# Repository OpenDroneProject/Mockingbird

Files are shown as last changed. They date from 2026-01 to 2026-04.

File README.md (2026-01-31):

# MockingBird

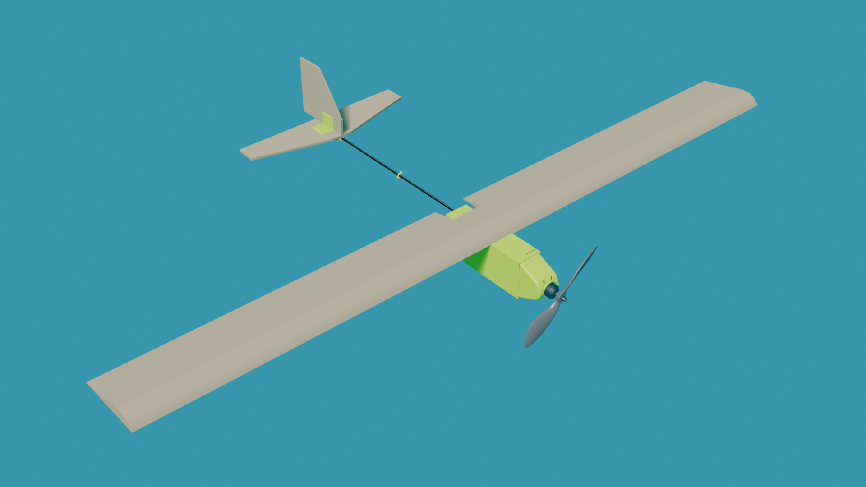
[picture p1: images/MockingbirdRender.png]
Mockingbird Render
    
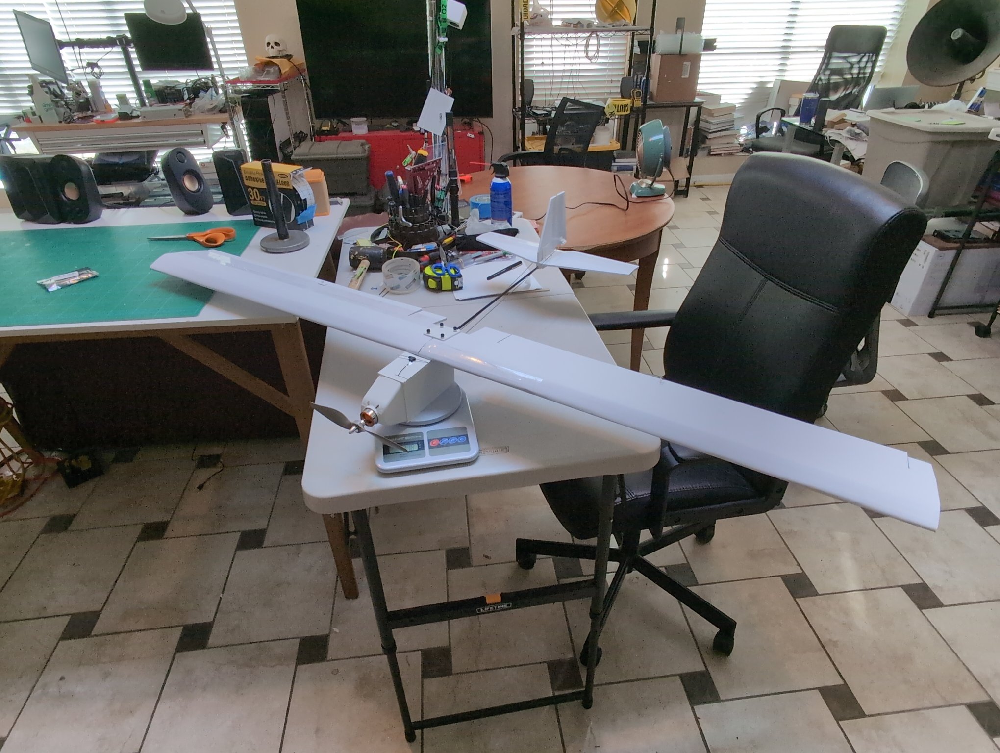
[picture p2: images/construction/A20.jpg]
Mockingbird Prototype
  

Mockingbird is intended to be the cheapest and simplest drone to make. Here are some stats:

- $90 cost per unit (not counting autonomy or FPV)
- Printable on a Bambu A1 Mini
- 745g (not counting autonomy or FPV)
- 1680g Static Thrust
- ~8 hours to build (most of that is 3D printer time)
- Adjustable Center of Lift
- Modular design, swap out the wings, tailfin, motor, battery, receiver, etc.

More detailed specs available on the [specs page](./SPECS.md).

[Bill of Materials](./BILL_OF_MATERIALS.md)  
[Assembly Guide](./ASSEMBLY.md)  
[Electronics Setup](./ELECTRONICS_SETUP.md)  

## Making the PDF
The `build_book.sh` script is a utility that turns the markdown files in this repo into a PDF.

If rust is not installed run `curl --proto '=https' --tlsv1.2 -sSf https://sh.rustup.rs | sh`

```bash
cargo install mdbook
./build_book.sh
mdbook serve book/
```

Download the webpage as a PDF, or run:
```bash
cargo install mdbook-pdf                                                      
mdbook-pdf book/
```

This file is large (~500MB), and will not be stored in this repository.

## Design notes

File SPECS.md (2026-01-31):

# Specs

| Parameter | Value |
|---|---|
| Weight (with battery) | 745g |
| Estimated Static Thrust | 1686g |
| Max TWR | 2.26 |

*Thrust estimated with 3S battery, 1400KV motor, 8x4E prop*

# Wing Specs

| Parameter | Value |
|---|---|
| Planform | Rectangular |
| Taper Ratio | 1 |
| Chord | 0.15m |
| Span | 1.524m |
| Area | 0.2286m² |
| Aspect Ratio | 10.15 |

---

## Aspect Ratio

Aspect ratio describes how long and narrow a wing is relative to its width. A high aspect ratio wing (like a glider) is long and thin, while a low aspect ratio wing (like a fighter jet) is short and wide.

```math
AR = \frac{S^2}{A} = \frac{Span}{Chord}
```

Where:
- **S** = Wingspan
- **A** = Wing area
- **Chord** = Wing width (for rectangular wings)

**Effects on performance:**
- **Higher AR** (like ours at 10.15): Lower induced drag, better lift-to-drag ratio, more efficient at slow speeds, better glide performance. Trade-off: requires stronger wing structure due to increased bending moment.
- **Lower AR**: Better roll rate and maneuverability, structurally stronger, but less aerodynamically efficient.

Our aspect ratio of ~10 is in the efficient range for slow-flying aircraft—similar to sailplanes and trainers.

---

## Wing Loading

Wing loading is the ratio of aircraft weight to wing area. It determines how "hard" the wing must work to generate lift and directly affects stall speed, handling, and flight characteristics.

```math
W_L = \frac{W}{A}
```

Where:
- **W** = Aircraft weight
- **A** = Wing area

**Effects on performance:**
- **Lower wing loading**: Slower stall speed, gentler handling, more affected by wind gusts, better for slow flight and easy landings.
- **Higher wing loading**: Faster stall speed, more stable in turbulence, better high-speed performance, but requires more runway.

---

## Stall Speed

Stall speed is the minimum airspeed at which the wing can generate enough lift to support the aircraft's weight. Below this speed, the wing stalls and lift drops dramatically.

Wing loading and stall speed are related by:

```math
W_L = \frac{1}{2} \rho V_{stall}^2 C_{L_{max}}
```

Solving for stall speed:

```math
V_{stall} = \sqrt{\frac{2 \cdot W_L}{\rho \cdot C_{L_{max}}}}
```

Where:
- **ρ (rho)** = Air density = 1.225 kg/m³ (at sea level)
- **C_L_max** = Maximum lift coefficient ≈ 1.5 (typical for flat-bottom airfoils)
- **W_L** = Wing loading (W/A)

---

## Glide Ratio (Estimated)

Glide ratio (L/D) is how far the aircraft travels forward for each unit of altitude lost—a 10:1 ratio means gliding 10m forward for every 1m of descent.

**Estimated glide ratio: ~8-10:1**

This estimate is based on:
- High aspect ratio (10.15) — reduces induced drag
- Rectangular planform — less efficient than tapered wings
- Flat-bottom airfoil — good for slow flight, not optimized for L/D
- Fuselage/pod — adds parasite drag

| Aircraft Type | Typical Glide Ratio |
|---|---|
| Typical RC trainer | 6-10:1 |
| **This plane (estimate)** | **~8-10:1** |
| Cessna 172 | ~9:1 |
| High-performance sailplane | 30-60:1 |

At 8:1, from 100m altitude you'd glide about 800m in still air.

---

## Performance Curves

**Wing Loading at 745g: ~3.3 kg/m²**

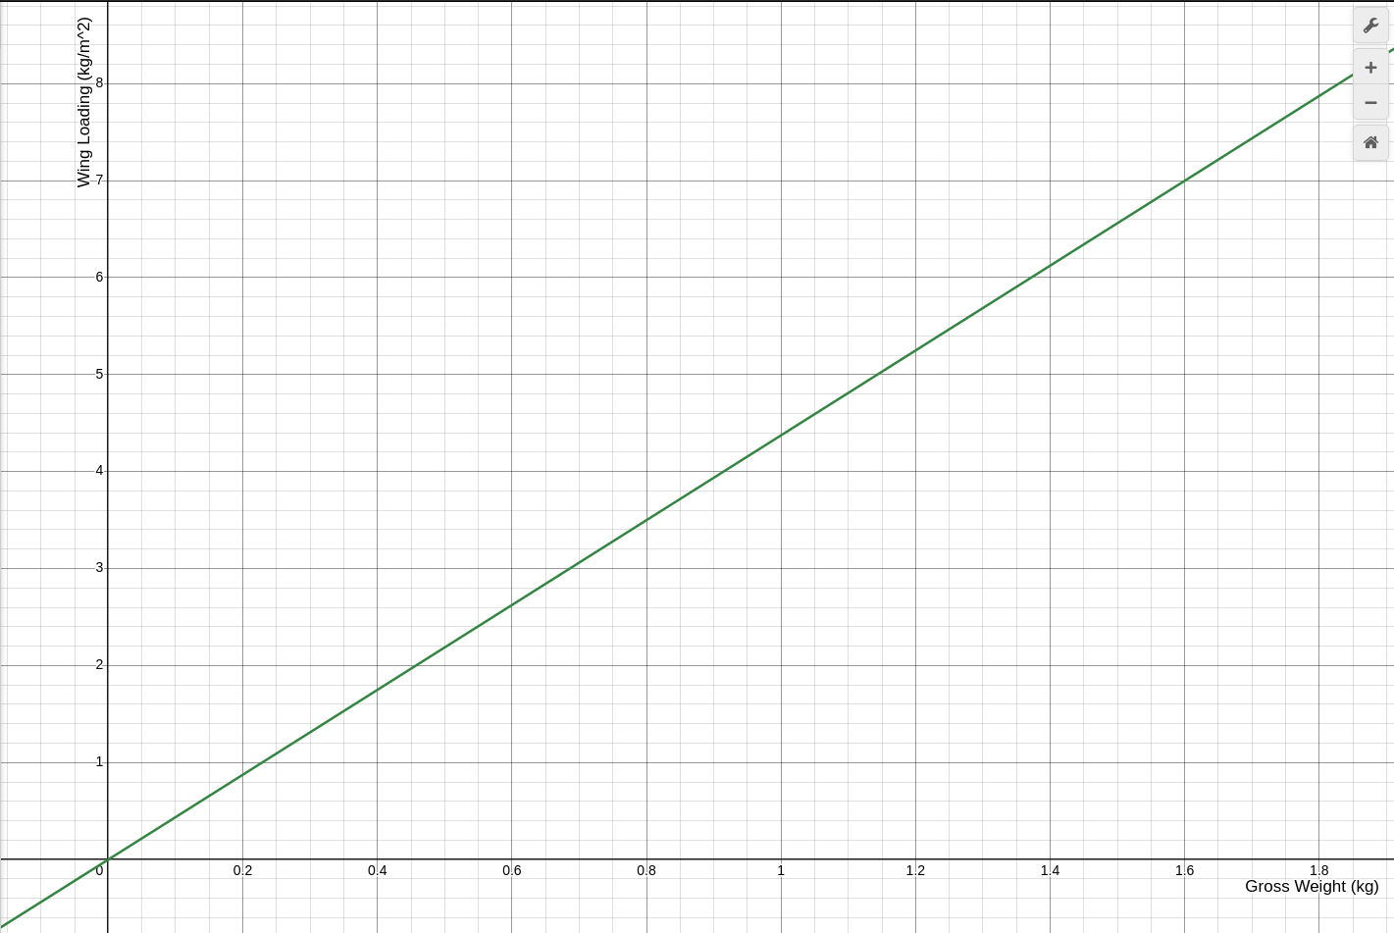
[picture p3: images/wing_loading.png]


**Stall Speed at 745g: ~5.8 m/s (13 mph)**

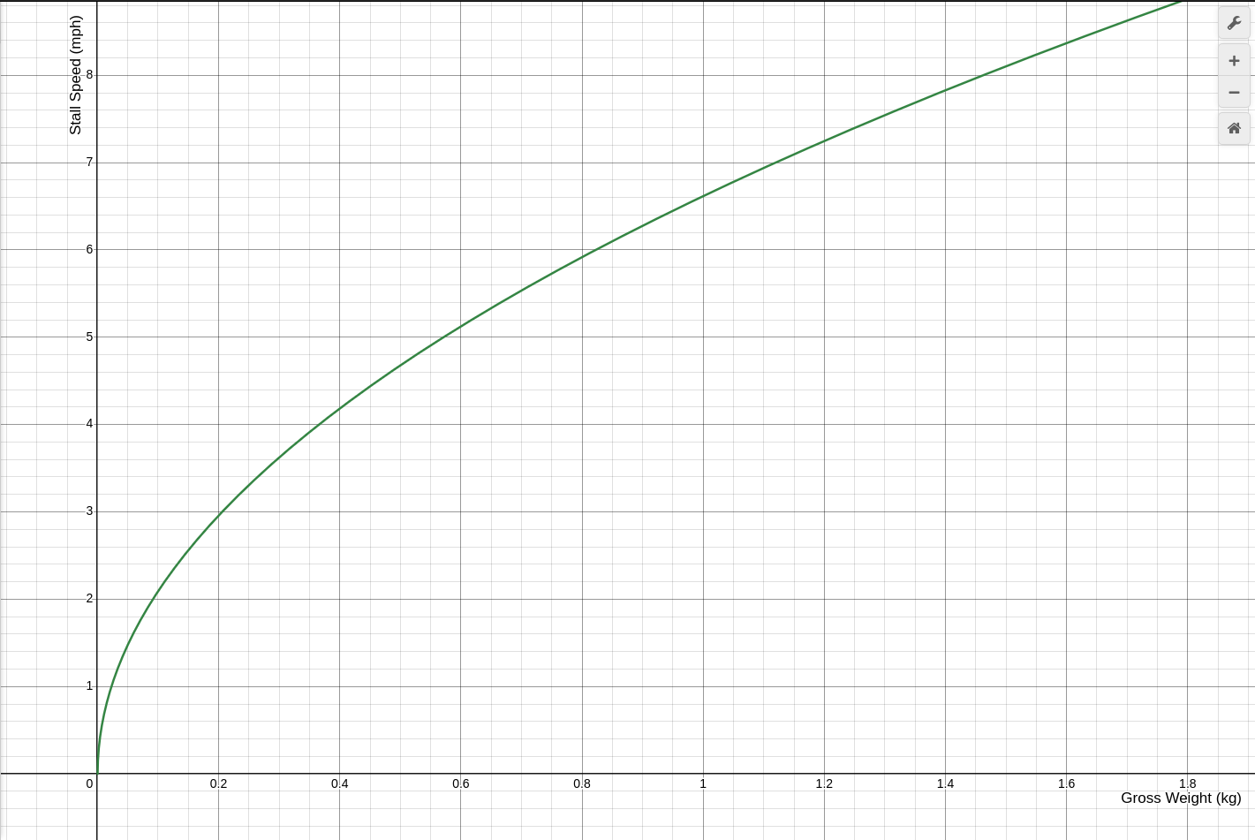
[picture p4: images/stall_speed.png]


---

## References

- [Aspect Ratio (Aeronautics) - Wikipedia](https://en.wikipedia.org/wiki/Aspect_ratio_(aeronautics))
- [How Does Aspect Ratio Affect Your Wing? - Boldmethod](https://www.boldmethod.com/learn-to-fly/aircraft-systems/how-does-aspect-ratio-affect-aircraft-wings/)
- [Aircraft Wing Area and Aspect Ratio - AeroToolbox](https://aerotoolbox.com/intro-wing-design/)
- [NASA Geometry Definitions](https://www.grc.nasa.gov/www/k-12/VirtualAero/BottleRocket/airplane/geom.html)

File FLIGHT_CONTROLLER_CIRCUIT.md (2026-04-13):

# Flight Controller Circuit Design

Custom fixed-wing flight controller stack designed for INAV. Supports IMU, GNSS, analog VTX, analog camera, and ELRS receiver. Servo and ELRS pins are hand-soldered Dupont headers by the end user.

---

## Development Strategy

A "strangler fig" approach is used — each custom board is validated against the SpeedyBee F405 Wing Mini before the next is designed. At every stage a fully functional flying system exists with only one new unknown variable.

| Stage | PDB | FC | Flasher |
|---|-----|----|---|
| 1 | SpeedyBee | SpeedyBee | **Ours** |
| 2 | **Ours** | SpeedyBee | Ours |
| 3 | Ours | **Ours** | Ours |

### Open Items Before Starting
- Measure the SpeedyBee FC board's USB extender connector pinout (physical silkscreen + continuity check)
- Measure the SpeedyBee PDB↔FC 12-pin stacking connector pinout (physical silkscreen + continuity check)

---

## Stack Architecture

Three permanent boards stack from bottom to top via 2×6 2.54mm stacking pin headers:

```
┌─────────────────────┐
│      FC Board       │  STM32F405, IMU, OSD, all JST connectors
└─────────────────────┘
           ↕  2×6 stacking header
┌─────────────────────┐
│      PDB Board      │  Battery input, 5V BEC, 6V BEC
└─────────────────────┘
```

The flasher accessory board is not a permanent stack member. It connects to the FC board via a cable when flashing is needed.

---

## Inter-Board Connectors

### PDB → FC (2×6 2.54mm stacking header)

| Pin | Row A | Row B |
|-----|---|---|
| 1 | GND | GND |
| 2 | GND | GND |
| 3 | VBAT | VBAT |
| 4 | 5V | 5V |
| 5 | 6V | 6V |
| 6 | SPARE | SPARE |

### FC → Flasher (JST SH 1.0mm 10-pin)

| Pin | Signal |
|-----|---|
| 1 | GND |
| 2 | GND |
| 3 | 5V |
| 4 | 3.3V |
| 5 | USB D+ |
| 6 | USB D− |
| 7 | BOOT0 |
| 8 | NRST |
| 9 | SWDIO |
| 10 | SWDCLK |

---

## Board 1: PDB (Power Distribution Board)

### Purpose
Battery input, spike suppression, reverse polarity protection, and regulated power output to the FC board.

### Large Solder Pads
- **Battery +/−** — main input, sized for XT30 (small wing) or XT60 (larger). Size for 16AWG minimum.
- **ESC +/−** — motor ESC wires solder directly here, on the same high-current copper pour as battery pads
- **Capacitor +/−** — for bulk low-ESR capacitor, same pour

Battery, ESC, and cap pads should all connect on the same wide copper pour. Keep traces short and fat.

### Bill of Materials

#### Power Input & Protection
| Component | Part | Notes |
|---|---|---|
| Bulk capacitor | Panasonic EEUFR1V471 — 470µF 35V low-ESR electrolytic | Through-hole solder pad footprint |
| TVS diode | SMBJ15A (3S) or SMBJ20A (4S) | Select based on max battery voltage |
| Reverse polarity MOSFET | AO4407 (SOP-8, 30V, 12A) | P-channel; gate resistor per datasheet |

#### 5V BEC (~2A)
Powers FC logic, GPS, ELRS, camera, VTX.

| Component | Part | Notes |
|---|---|---|
| Regulator IC | MP2315GJ-Z | 3A synchronous buck, up to 24V input |
| Inductor | Würth 744043100 — 10µH 3A | Or equivalent |
| Supporting passives | Per MP2315 datasheet | Bootstrap cap, input/output caps, feedback resistors |

#### 6V BEC (~3A)
Powers servos.

| Component | Part | Notes |
|---|---|---|
| Regulator IC | MP1584EN | 3A adjustable buck, up to 28V input |
| Inductor | Würth 744043047 — 4.7µH 3A | Or equivalent |
| Supporting passives | Per MP1584 datasheet | Output voltage set by feedback resistor divider |

#### Connectors & Indicators
| Component | Part | Notes |
|---|---|---|
| Stack header | 2×6 2.54mm male through-hole pin header | Pins pointing up toward FC board |
| Battery pads | Large through-hole pads, 2mm drill | Size for 16AWG wire minimum |
| ESC pads | Large through-hole pads, 2mm drill | Same |
| Capacitor pads | Through-hole pads to match cap lead spacing | Match EEUFR1V471 footprint |
| Power LED | 0402 red LED + 1kΩ resistor | On 5V rail |

### Implementation Plan

1. **Schematic (KiCad)**
   - Draw reverse polarity protection: AO4407 gate tied to GND through resistor, source on VBAT+, drain feeds internal VBAT rail
   - Draw 5V BEC using MP2315 application circuit from datasheet
   - Draw 6V BEC using MP1584 application circuit — set output to 6V via feedback resistor values (datasheet provides formula)
   - Connect VBAT, 5V, 6V, and GND pins to the 2×6 stack connector symbol
   - Add large pad symbols for battery, ESC, and capacitor

2. **Layout (KiCad)**
   - Place battery, ESC, and cap pads first along one edge
   - Place TVS and reverse polarity MOSFET immediately adjacent to battery pads, before anything else in the power path
   - Place each BEC circuit close to its output pin on the stack connector
   - Flood the board with GND and VBAT copper pours on opposite layers — keep high-current paths wide and short
   - Route 5V and 6V as wide traces from BEC output caps to stack connector
   - Keep BEC switching nodes (SW pin, inductor) compact to minimize EMI
   - Place power LED near the stack connector edge

3. **Review**
   - Run KiCad DRC — zero errors before ordering
   - Manually verify feedback resistor values produce correct output voltages
   - Check inductor and capacitor voltage/current ratings against worst-case inputs

4. **Fabrication**
   - 2-layer board is sufficient — no high-speed signals
   - Order from JLCPCB; hand-solder through-hole components, SMT assembly optional for BEC ICs

### Success Criteria

**Before applying power**
- Continuity between all GND pads
- No continuity between VBAT, 5V, 6V, or GND rails to each other
- High resistance (MOhm range) from VBAT+ to VBAT− — confirms no dead shorts

**On first power-up**
- Use a bench PSU set to battery voltage with 500mA current limit — if it folds back immediately there is a short
- Power LED illuminates
- Stack connector pin readings:

| Pin | Expected |
|-----|---|
| GND | 0V reference |
| VBAT | Matches PSU output |
| 5V | 4.9–5.1V |
| 6V | 5.9–6.1V |
| All other pins | 0V or floating |

**Under load**
- Connect dummy load (~500mA on 5V, ~1A on 6V) — voltages stay within ±0.2V of target
- BEC ICs and inductors warm but not hot after 60 seconds

---

## Board 2: FC Board (Flight Controller)

### Purpose
Main flight controller. Hosts the STM32F405RGT6, IMU, OSD chip, and all external connectors for GPS, ELRS, camera, and VTX.

### Bill of Materials

#### Microcontroller
| Component | Part | Notes |
|---|---|---|
| MCU | STM32F405RGT6 | LQFP-64 |
| HSE crystal | Abracon ABM8-8.000MHZ-B2-T — 8MHz | ±20ppm |
| Crystal load caps | 22pF 0402 × 2 | Per crystal datasheet |
| VCAP caps | 1µF 0402 × 2 | VCAP1 and VCAP2 — must be isolated from 3.3V rail |
| BOOT0 pull-down | 10kΩ 0402 | Boots from flash by default; stack/flasher connector overrides |
| NRST filter cap | 100nF 0402 | |
| Decoupling caps | 100nF + 4.7µF at every VDD/VDDA/VDDIO pin | Per STM32F405 datasheet |

> **Note:** VCAP1 and VCAP2 are the output pins of the STM32's internal 1.2V core regulator. They require dedicated 1µF caps to GND and must NOT connect to the 3.3V net. This is a common first-timer mistake.

#### Power
| Component | Part | Notes |
|---|---|---|
| 3.3V LDO | AP2112K-3.3 | SOT-25; takes 5V from stack connector |
| Decoupling caps | Per AP2112K datasheet | |

#### IMU
| Component | Part | Notes |
|---|---|---|
| IMU | ICM-42688-P | SPI interface |
| VDD ferrite bead | 100Ω @ 100MHz | Filters switching noise on IMU supply |
| Decoupling caps | 100nF + 1µF | Per ICM-42688-P datasheet |

#### OSD
| Component | Part | Notes |
|---|---|---|
| OSD chip | AT7456E | SPI to MCU; sits in the video path between camera and VTX |
| Decoupling caps | Per AT7456E datasheet | |

#### JST SH 1.0mm Receptacles
| Connector | Pins | Signals |
|---|---|---|
| GPS | 4 | GND, 5V, TX, RX |
| ELRS | 4 | GND, 5V, TX, RX |
| Camera | 3 | GND, 5V, video in → AT7456E |
| VTX | 4 | GND, 5V, video out from AT7456E, SmartAudio UART TX |

#### Servo Output Pads
- Through-hole 3-pin groups (GND, 6V, signal) × 6
- End user hand-solders male Dupont headers
- Suggested channels: aileron ×2, elevator, rudder, throttle, flaps

#### Voltage Sensing
- Resistor divider from VBAT (stack connector) to STM32 ADC pin
- Allows INAV to report battery voltage in OSD and trigger low-voltage warnings

#### Indicators & Misc
| Component | Part | Notes |
|---|---|---|
| Status LED | 0402 LED + resistor | GPIO-controlled; INAV uses for arming state |
| Buzzer pad | 2-pin through-hole | Passive buzzer for INAV alerts and lost-model beeper |

#### Connectors
| Component | Part | Notes |
|---|---|---|
| PDB stack connector | 2×6 2.54mm female socket (bottom of board) | Mates with PDB stacking header |
| Flasher connector | JST SH 1.0mm 10-pin receptacle | For flasher accessory board cable |

---

## Board 3: Flasher Accessory Board

### Purpose
Connects to the FC board to provide USB-C flashing capability. Not a permanent stack member — attach when flashing, remove during flight. Designed in two versions: one compatible with the SpeedyBee F405 Wing Mini (Stage 1), and one for our custom FC board (Stage 3).

### Stage 1: SpeedyBee-Compatible Flasher

The SpeedyBee FC board exposes a programming interface via its "Wireless USB Extender" connector. Our flasher board mates with this connector and replaces the SpeedyBee wireless extender with a direct USB-C connection.

> **Required before design:** Measure the SpeedyBee FC board's USB extender connector — note connector type, pin count, and silkscreen labels. Confirm with continuity check which pins carry D+, D−, 5V, GND, and whether BOOT0/NRST are exposed.

#### Bill of Materials

| Component | Part | Notes |
|---|---|---|
| USB-C receptacle | GCT USB4135-GF-A | Mid-mount, low profile |
| ESD protection | USBLC6-2SC6 | On D+, D−, and VBUS |
| CC resistors | 5.1kΩ 0402 × 2 | CC1 and CC2 to GND — mandatory for USB-C device role |
| BOOT button | 3×6mm SMD tactile switch | Pulls BOOT0 high if SpeedyBee exposes it; otherwise used only for our custom FC |
| RESET button | 3×6mm SMD tactile switch | Pulls NRST low if SpeedyBee exposes it; otherwise used only for our custom FC |
| Power LED | 0402 LED + 1kΩ resistor | Confirms VBUS is live |
| Decoupling caps | 10µF + 100nF on VBUS | |
| FC connector | TBD — match SpeedyBee USB extender port | Pinout to be measured from physical board |

#### Flashing Procedure (SpeedyBee)
1. Plug flasher board into SpeedyBee USB extender port
2. Connect USB-C to computer
3. Enter DFU mode per SpeedyBee's method (may differ from our custom FC)
4. Flash via INAV Configurator

---

### Stage 3: Custom FC Flasher

Once the custom FC board is designed, the flasher connects via JST SH 1.0mm 10-pin cable. The BOM is identical to the Stage 1 flasher except the FC connector changes.

| Component | Part | Notes |
|---|---|---|
| USB-C receptacle | GCT USB4135-GF-A | Mid-mount, low profile |
| ESD protection | USBLC6-2SC6 | On D+, D−, and VBUS |
| CC resistors | 5.1kΩ 0402 × 2 | CC1 and CC2 to GND |
| BOOT button | 3×6mm SMD tactile switch | Pulls BOOT0 high via JST connector |
| RESET button | 3×6mm SMD tactile switch | Pulls NRST low via JST connector |
| Power LED | 0402 LED + 1kΩ resistor | Confirms VBUS is live |
| Decoupling caps | 10µF + 100nF on VBUS | |
| JST SH 1.0mm receptacle | 10-pin | Connects to custom FC board |

#### Flashing Procedure (Custom FC)
1. Connect flasher board to FC board via JST cable
2. Hold BOOT button
3. Press and release RESET
4. Release BOOT — MCU is now in USB DFU mode
5. Open INAV Configurator and flash firmware

> No LDO needed on either flasher version. 5V from VBUS passes directly to the FC board. The custom FC board's AP2112K generates 3.3V from that; the SpeedyBee has its own onboard regulation.

---

## Cost Estimates

Rough estimates for a first run of 5 boards from JLCPCB, components sourced from LCSC.

### Per-Board Component Cost

#### Flasher Board (~$4–6)
| Item | Cost |
|---|---|
| PCB (2-layer, ~30×20mm, qty 5) | ~$0.50 |
| GCT USB4135-GF-A | ~$0.80 |
| USBLC6-2SC6 | ~$0.30 |
| Tactile switches ×2 | ~$0.20 |
| JST SH 1.0mm 10-pin receptacle | ~$0.40 |
| Passives, LED | ~$0.20 |
| **Total** | **~$2.40** |

#### PDB (~$8–12)
| Item | Cost |
|---|---|
| PCB (2-layer, ~40×40mm, qty 5) | ~$0.60 |
| MP2315GJ-Z (5V BEC) | ~$1.20 |
| MP1584EN (6V BEC) | ~$0.80 |
| Würth inductors ×2 | ~$2.50 |
| Panasonic EEUFR1V471 cap | ~$0.80 |
| AO4407 MOSFET | ~$0.40 |
| SMBJ15A TVS | ~$0.30 |
| 2×6 pin header | ~$0.30 |
| Passives, LED | ~$0.30 |
| **Total** | **~$7.20** |

#### FC Board (~$25–35)
| Item | Cost |
|---|---|
| PCB (4-layer, ~35×35mm, qty 5) | ~$2.50 |
| STM32F405RGT6 | ~$7.00 |
| ICM-42688-P | ~$3.50 |
| AT7456E | ~$3.00 |
| AP2112K-3.3 LDO | ~$0.40 |
| 8MHz crystal | ~$0.40 |
| JST SH 1.0mm receptacles ×4 | ~$1.60 |
| 2×6 female socket + JST SH 10-pin | ~$0.60 |
| Passives, LED, crystal caps | ~$1.50 |
| **Total** | **~$20.50** |

### First-Run Total (qty 5)

| Board | Components | PCB | JLCPCB SMT Setup | First Run (qty 5) |
|---|---|-----|---|---|
| Flasher | ~$12 | ~$2.50 | ~$15 | ~$30 |
| PDB | ~$36 | ~$3 | ~$20 | ~$60 |
| FC | ~$103 | ~$12.50 | ~$30 | ~$145 |
| **Total** | | | | **~$235** |

### Notes
- JLCPCB SMT setup fees (~$8–20 per unique extended part) dominate at low quantities — per-unit cost drops significantly at qty 10+
- The STM32F405RGT6 is the single biggest cost driver — fine-pitch LQFP-64, SMT assembly strongly recommended over hand-soldering
- ICM-42688-P and AT7456E are also fine-pitch and should be assembled by JLCPCB
- Parts in JLCPCB's Basic parts library have no setup fee — check there first when choosing passives and common ICs
- A second revision typically costs much less since setup fees are not paid again

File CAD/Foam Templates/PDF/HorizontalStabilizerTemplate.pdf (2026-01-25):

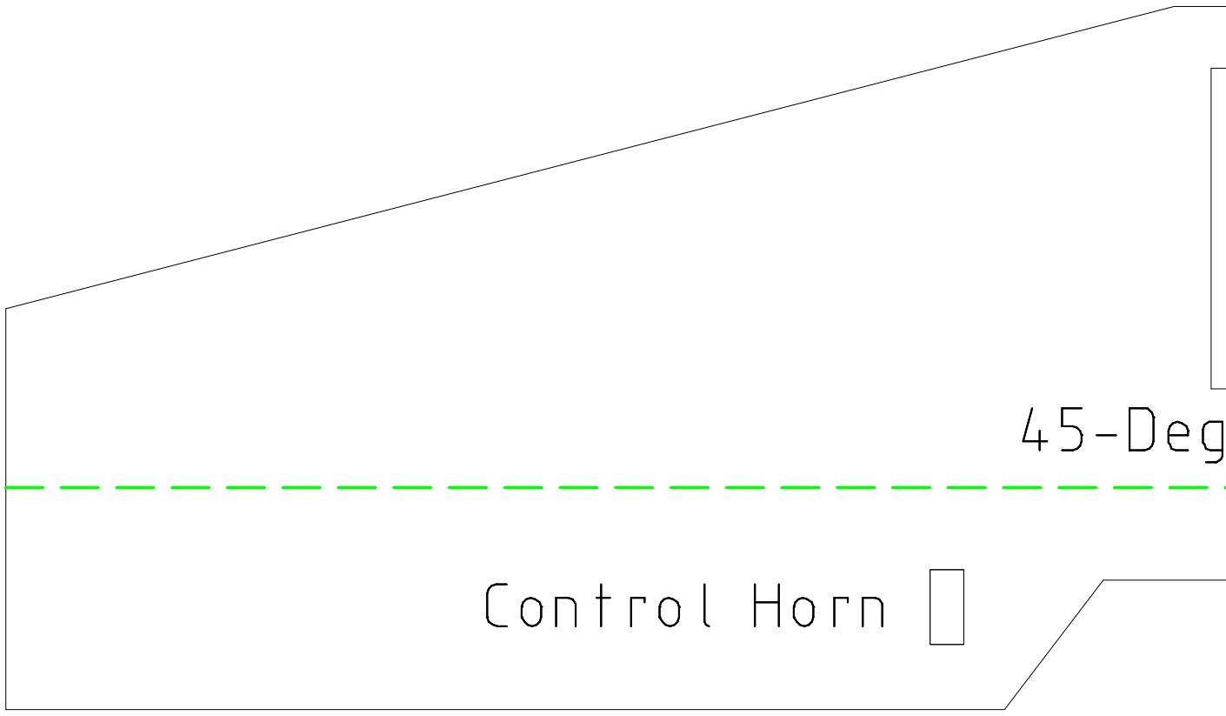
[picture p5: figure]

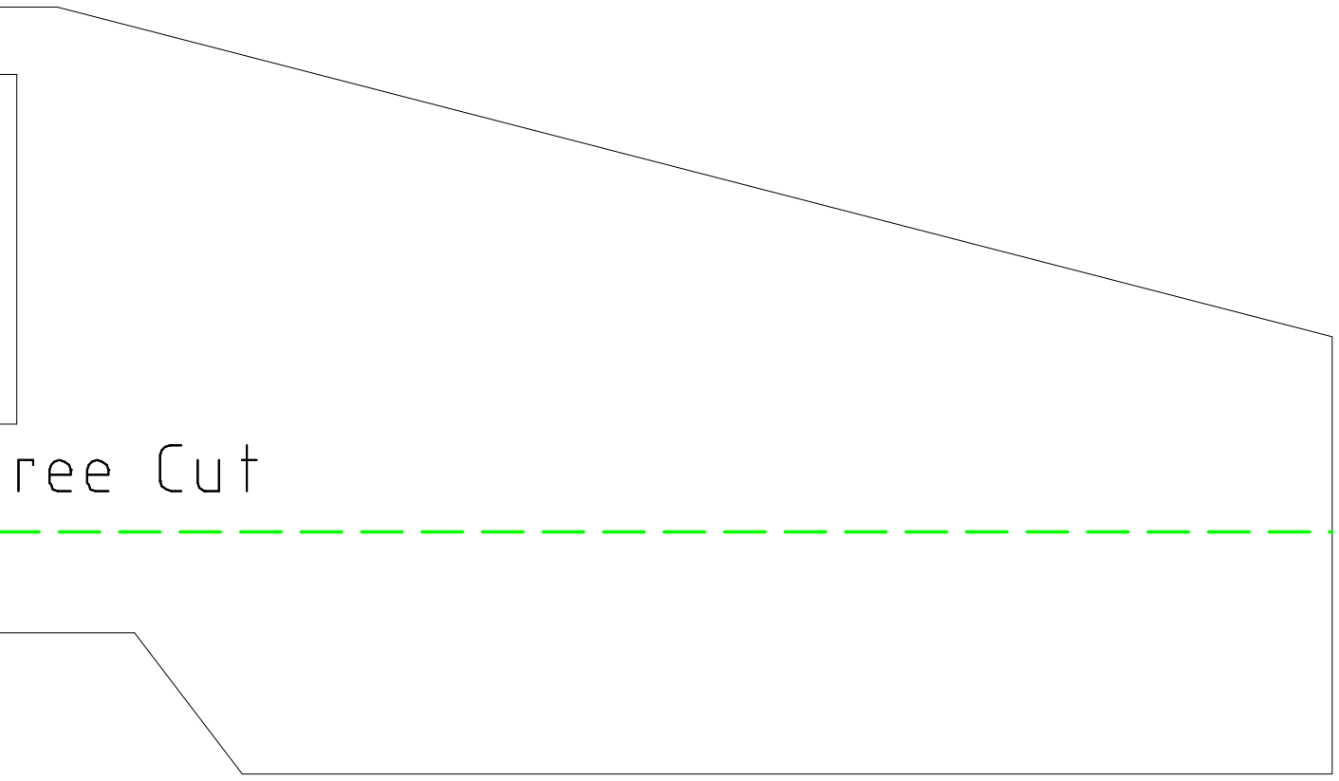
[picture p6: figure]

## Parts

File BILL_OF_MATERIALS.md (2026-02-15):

# Bill of Materials

## Tools

Comprehensive list of tools you will need for this build.

### Assembly

| Item |
|------|
| Bambu A1 Mini or Larger |  
| X-Acto knife |  
| Cutting surface |  
| Metal Ruler |
| Large Hot Glue gun | 
| Large Hot Glue sticks | 
| Packing tape | 
| Fine sharpie | 
| Masking tape | 
| Twist ties (optional) | 
| Hex wrench set | 
| Small phillips head screwdriver | 
| Needle-nose pliers | 

### Flying

Any ELRS radio running EdgeTX or OpenTX will work. I just have the Radiomaster Pocket and I like it a lot for the price.

| Item | Cost | Link |
|---|---|---|
| RadioMaster Pocket | $80 | [link](https://www.amazon.com/Radiomaster-Pocket-Transmitter-Lightweight-ELRS-Charcoal/dp/B0DXPLH726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) |
| 18650 Battery for radio (2x) | $16 | [link](https://www.amazon.com/JESSY-Rechargeable-Battery-3-7V-Flashlights/dp/B0FCMD13RR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) |
| Battery Charger (2S/3S, XT60, balance socket) | $30-$50 | [link](https://www.amazon.com/Battery-Charger-Balance-Discharger-Batteries/dp/B0F5HPV5BR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) |

### Electronics Work

You will need a soldering iron to set up the SpeedyBee F405 Wing Mini. I recommend the Pinecil if you want something that doesn't take up a lot of space, although it is not particularly ergonomic.

| Item | Cost | Link |
|---|---|---|
| Pinecil soldering iron | $40 | [link](https://www.amazon.com/PINECIL-Smart-Mini-Portable-Soldering/dp/B096X6SG13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) |
| 100W USB-C charger for Pinecil | $30 | [link](https://www.amazon.com/Charger-Anker-Compact-Foldable-Included/dp/B0C1FZWT8M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) |
| Practice soldering boards (optional) | $14 | [link](https://www.amazon.com/Soldering-Practice-Beginner-Improving-Controller/dp/B0C5RBTHT1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) |

## Materials

### Materials Required for Base Drone Build

| Item | cost | qty for planes | cost per unit | Link |
|---|---|---|---|---|
| Adhesive Velcro | $10 | 360 | $0.03 | [link](https://www.amazon.com/dp/B0CGVPMJBP?ref=ppx_yo2ov_dt_b_fed_asin_title&th=1) |
| M2 screws | $10 | 25 | $0.40 | [link](https://www.amazon.com/Fgruh-1260pcs-M2-Assortment-Stainless/dp/B0FG2CC91J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) |
| M4 screws | $4 | 10 | $0.40 | [link](https://www.amazon.com/Assortment-Stainless-Washers-Printing-Projects/dp/B0DLNL2XJT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) |
| Push rods | $13 | 10 | $1.30 | [link](https://www.amazon.com/dp/B0B2LCJDPF?ref=ppx_yo2ov_dt_b_fed_asin_title) |
| 1.2mm wire | $10 | 20 | $0.50 | [link](https://www.amazon.com/uxcell-10Pcs-Stainless-Steel-Working/dp/B0DKXSRDC5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) |
| ELRS receiver | $19 | 1 | $19 | [link](https://www.amazon.com/dp/B09WHLJ2GN?ref=ppx_yo2ov_dt_b_fed_asin_title) |
| 30A ESC with XT60 and bullet plugs | $17 | 2 | $8.50 | [link](https://www.amazon.com/Electric-Brushless-Controller-Airplane-Helicopter/dp/B0CZNM4H7H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) |
| 9g servo | $16 | 2.5 | $6.40 | [link](https://www.amazon.com/dp/B09GFN98X9?ref=ppx_yo2ov_dt_b_fed_asin_title&th=1) |
| 5mm x 500mm carbon fiber rods | $10 | 5 | $2.00 | [link](https://www.amazon.com/MECCANIXITY-Carbon-Fiber-300mm-Quadcopter/dp/B0CTTBSBNN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) |
| 5mm OD x 4mm ID x 500mm L aluminum tube | $7  | 4 | $1.75 | [link](https://www.aliexpress.us/item/3256805305625604.html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) |
| PETG filament | $17 | 40 | $0.43 | [link](https://www.amazon.com/dp/B0FGTVG684?ref=ppx_yo2ov_dt_b_fed_asin_title&th=1) |
| AIR PLA filament | $25 | 40 | $0.63 | [link](https://www.amazon.com/OVERTURE-Filament-Cardboard-Dimensional-Probability/dp/B0BQRF32YY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) |
| 20"x30" 5mm foamboard | $28 | 5 | $5.60 | [link](https://www.amazon.com/UCreate%C2%AE-Board-White-Matte-Sheets/dp/B074QZMLQF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) |
| 2200mAh 3S | $34 | 2 | $17 | [link](https://www.amazon.com/OVONIC-2200mAh-Battery-Evader-Airplane/dp/B07DGSVNP5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) |
| 800-1400kv BR2208 motor | $12 | 1 | $12 | [link](https://www.amazon.com/dp/B08QZ95C98?ref=ppx_yo2ov_dt_b_fed_asin_title&th=1) |
| 6" servo cables | $10 | 2.5 | $4 | [link](https://www.amazon.com/dp/B07QJSWNFM?ref=ppx_yo2ov_dt_b_fed_asin_title) |
| servo Y-cable | $10 | 10 | $1 | [link](https://www.amazon.com/dp/B0CM6M6DKK?ref=ppx_yo2ov_dt_b_fed_asin_title&th=1) |
| 8x4 properller | $13 | 10 | $1.30 | [link](https://www.amazon.com/uxcell-Propellers-Fixed-Wing-Airplane-Adapter/dp/B07PWD3DSB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) |

**Startup Cost: $262**  
**Cost Per Unit: $88**

### BOM for Autonomy Upgrade

| Item | cost | qty for planes | cost per unit | Link |
|---|---|---|---|---|
| Speedybee F405 wing MINI | $36 | 1 | $36 | [link](https://www.speedybee.com/speedybee-f405-wing-mini-fixed-wing-flight-controller/) |
| XT60 cables | $16 | 10 | $1.60 | [link](https://www.amazon.com/dp/B0DPCFN6QT?ref=ppx_yo2ov_dt_b_fed_asin_title&th=1) |
| ELRS non-PWM | $24 | 1 | $24 | [link](https://www.amazon.com/dp/B0BGBKG635?ref=ppx_yo2ov_dt_b_fed_asin_title) |
| Beitian BN220 | $12 | 1 | $12 | [link](https://www.aliexpress.us/item/3256806167148761.html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) |

**Cost Per Unit: $74**

### BOM for FPV Upgrade

| Item | cost | qty for planes | cost per unit | Link |
|---|---|---|---|---|
| Camera  | $19 | 1 | $19 | [link](https://www.amazon.com/dp/B09SL2TRYF?ref=ppx_yo2ov_dt_b_fed_asin_title&th=1) |
| Antenna | $10 | 1 | $10 | [link](https://www.amazon.com/dp/B076H5QT2N?ref=ppx_yo2ov_dt_b_fed_asin_title&th=1) |
| VTX | $30 | 1 | $30 | [link](https://www.amazon.com/dp/B07YC1BSX6?ref=ppx_yo2ov_dt_b_fed_asin_title) |

**Cost Per Unit: $60**

# Mass Budget

## Electronics

| Item | Weight per unit | Qty | Total |
|---|---|-----|---|
| Battery | 172g | 1 | 172g  |
| ESC | 32g | 1 | 32g |
| ELRS Receiver | 15g | 1 | 15g |
| Motor | 41g | 1 | 41g |
| SG 90 Servos | 19g | 4 | 36g |
| 6" Servo Extenders  | 10g | 2 | 20g |
| Y Servo splitter | 10g | 1 | 10g |
| Velcro | ??? | ? | ??? |
| | | | 328g  |

## Aerofoils

| Item | Weight per unit | Qty | Total |
|---|---|-----|---|
| Wings | 220g | 1 | 220g  |
| Carbon Fiber Rod | 11g | 2 | 22g |
| Tailfin Assembly | 27g | 1 | 27g |
| M4 Screws | 3g | 4 | 12g |
| | | | 267g  |

## Pod

| Item | Weight per unit | Qty | Total |
|---|---|-----|---|
| Motor Mount | 18g | 1 | 18g |
| Pod | 56g | 1 | 56g |
| M2 Screws | 1.5g | 18  | 27g |
| Servo Holder | ??? | 2 | ??? |
| Front Fairing | ??? | 1 | ??? |
| Rear Fairing | ??? | 1 | ??? |
| Bottom Fairing | ??? | 1 | ??? |
| | | | 101g  |

TOTAL: 718g  
ACTUAL MEASURED: 745g  

## Autonomy
flight computer -- 42g
GNSS -- 15g

TOTAL + Autonomy: 780g

## FPV

TODO

## Construction Time

### 3D Printing Time

| Part | Time |
|---|---|
| Electronics Pod | 2hrs 20 mins |
| Motor Mount | 1hr 10 mins |
| Small Parts | 2hrs 30 mins |
| Front Fairing | 45 mins |
| Bottom Fairing | 1hr |
| Rear Fairing | ? |
| Top Fairing | 15 mins |
| Servo Fairings | 45 mins |
| **Total** | **6hr 45 mins** |

### Foamboard

| Task | Time |
|---|---|
| Template Print and Cutout | 20 mins (only needed first time) |
| Tailfin Cutout | 5 mins |
| Wing Fold | 30 mins per wing |
| **Total** | **~1hr** |

### Assembly

| Task | Time |
|---|---|
| Wing assembly | 30 mins |
| Body assembly | 30 mins |

### Testing and Electronics Config
??? Min

### Total

3D printing can be done while making the templates.

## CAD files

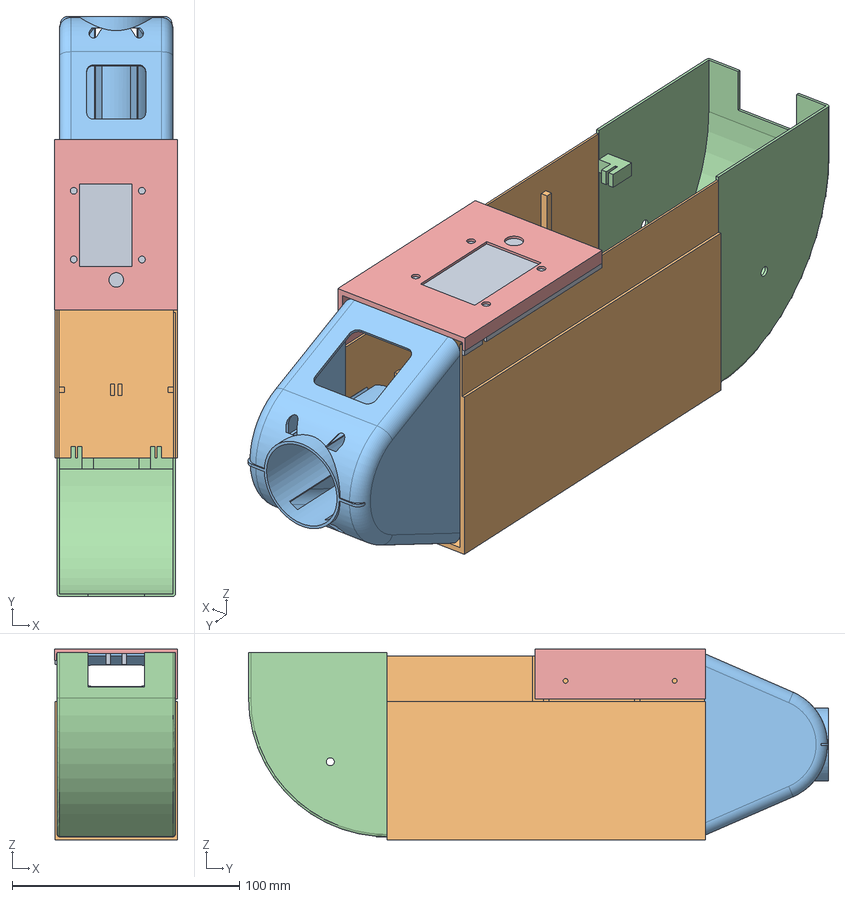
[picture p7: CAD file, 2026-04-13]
CAD/3D Printed Parts/FreeCAD Source Files/Mockingbird.FCStd
54.2 x 255.2 x 84.0 mm
TopFairing
BottomFairing
FrontFairing
RearFairing
TopFairingVTX

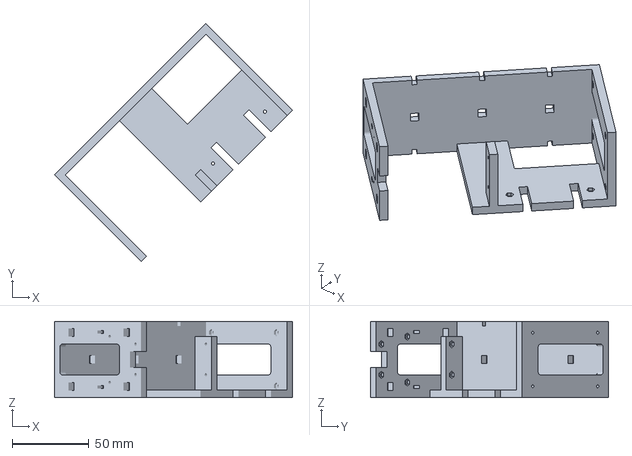
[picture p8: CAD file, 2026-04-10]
CAD/3D Printed Parts/GCODE/POD.3mf
155.6 x 155.6 x 50.0 mm

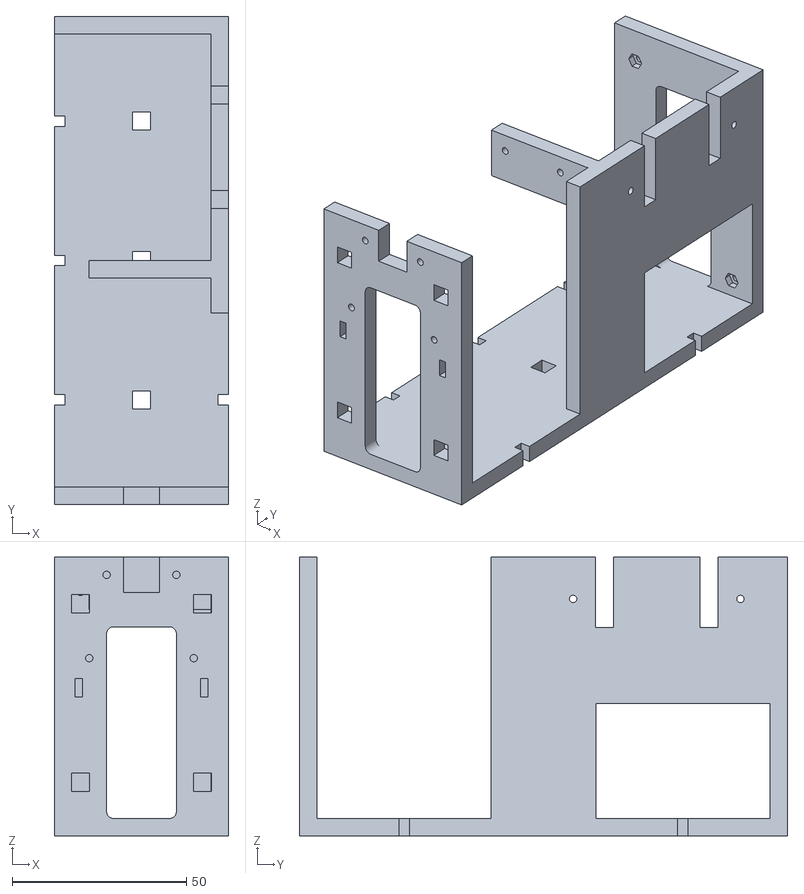
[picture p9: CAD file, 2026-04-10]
CAD/3D Printed Parts/STL/Pod.stl
50.0 x 140.0 x 80.0

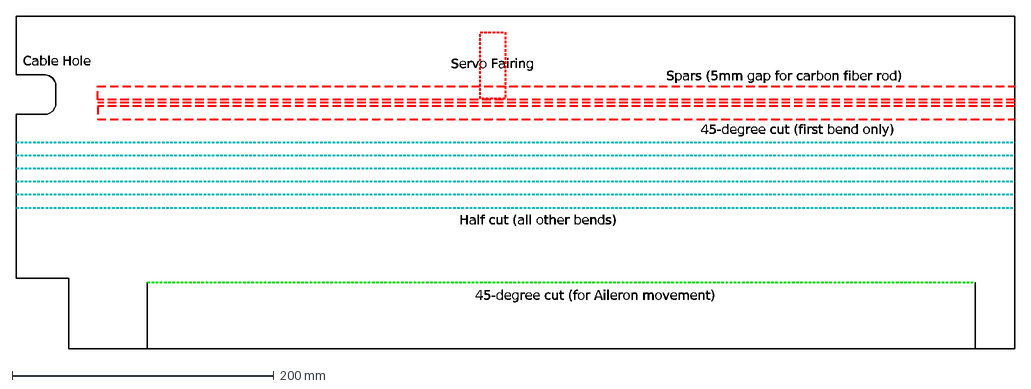
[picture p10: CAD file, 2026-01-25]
CAD/Foam Templates/DXF/LeftWingTemplate.dxf
Spars (5mm gap for carbon fiber rod)
Servo Fairing
Cable Hole
Half cut (all other bends)
45-degree cut (first bend only)
45-degree cut (for Aileron movement)

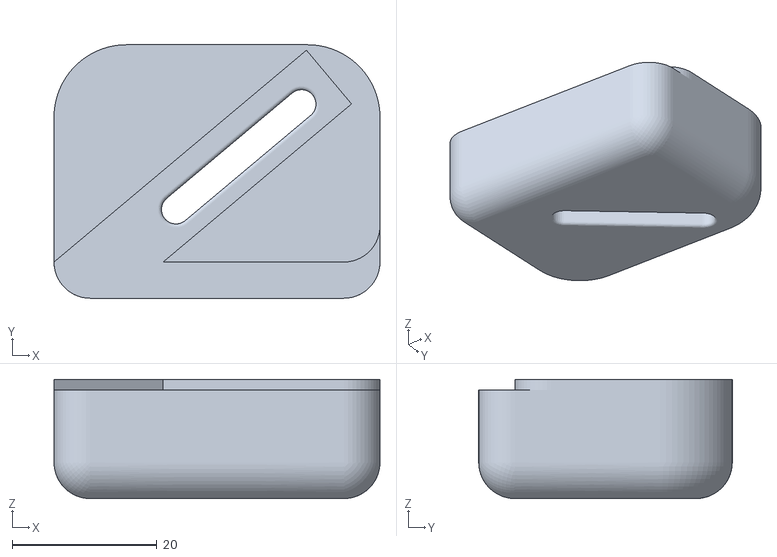
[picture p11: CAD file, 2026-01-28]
Utilities/Foam_board_90_degree_cutter.stl
45.0 x 35.0 x 16.5

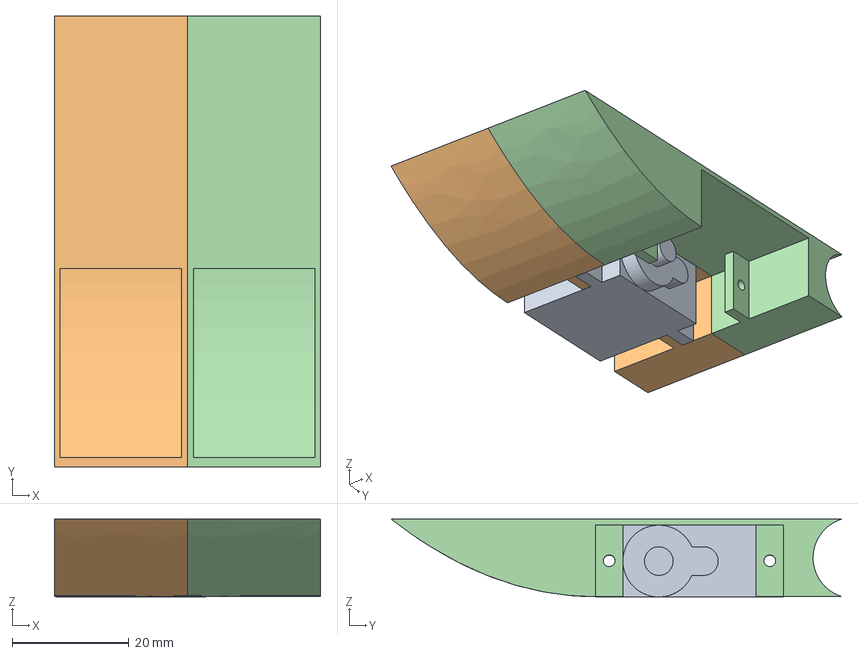
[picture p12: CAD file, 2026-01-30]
CAD/3D Printed Parts/FreeCAD Source Files/ServoFairing.FCStd
45.6 x 77.2 x 13.4 mm
ServoRef
LeftFairing
RightFairing

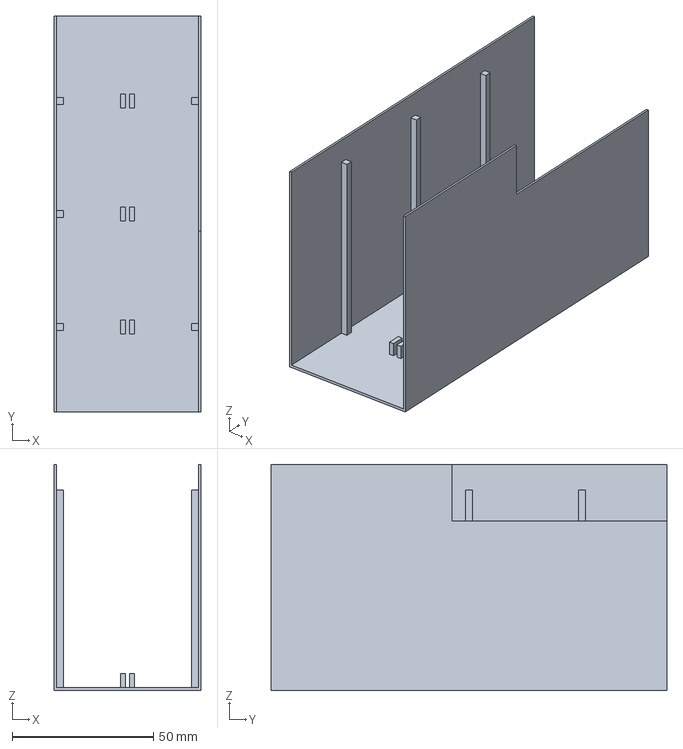
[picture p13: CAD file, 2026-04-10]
CAD/3D Printed Parts/GCODE/BOTTOM_FAIRING.3mf
52.0 x 140.0 x 80.0 mm

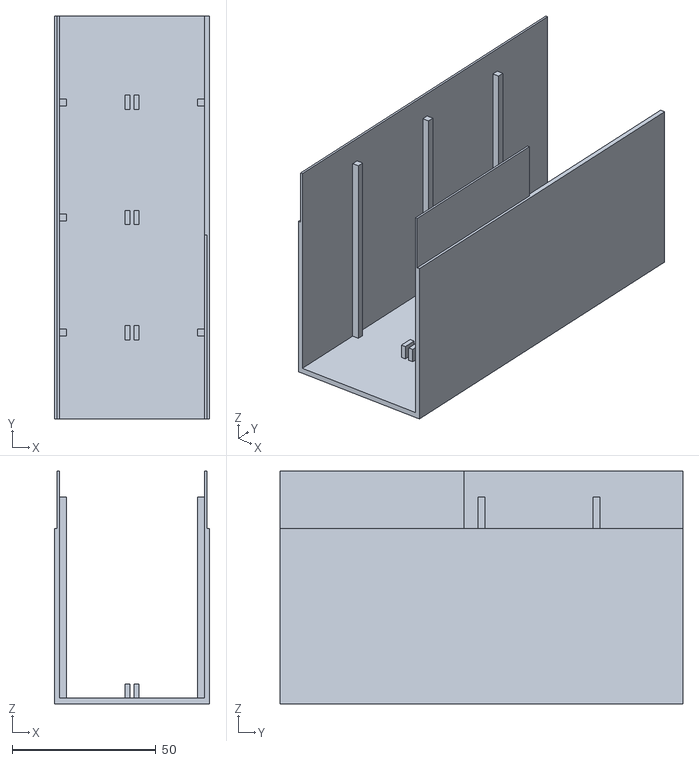
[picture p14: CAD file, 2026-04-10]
CAD/3D Printed Parts/STL/BottomFairing.stl
54.0 x 140.0 x 81.0

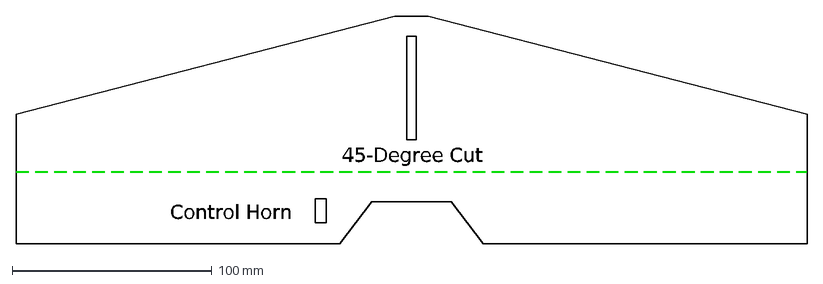
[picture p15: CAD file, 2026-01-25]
CAD/Foam Templates/DXF/HorizontalStabilizerTemplate.dxf
Control Horn
45-Degree Cut

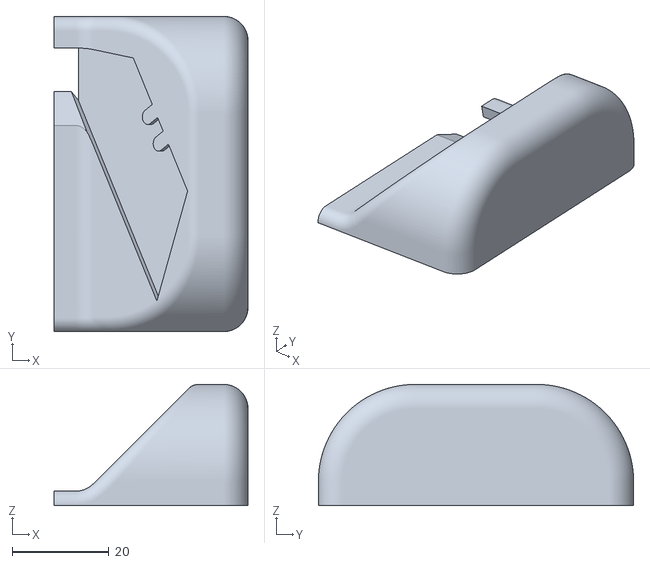
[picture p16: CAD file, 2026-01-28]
Utilities/5mmFoamBoardMiterCutter.stl
40.0 x 65.0 x 25.0

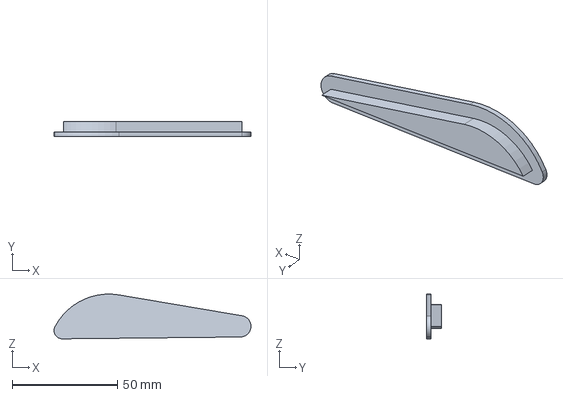
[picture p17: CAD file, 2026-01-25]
CAD/3D Printed Parts/FreeCAD Source Files/Winglet.FCStd
93.7 x 7.00 x 21.3 mm

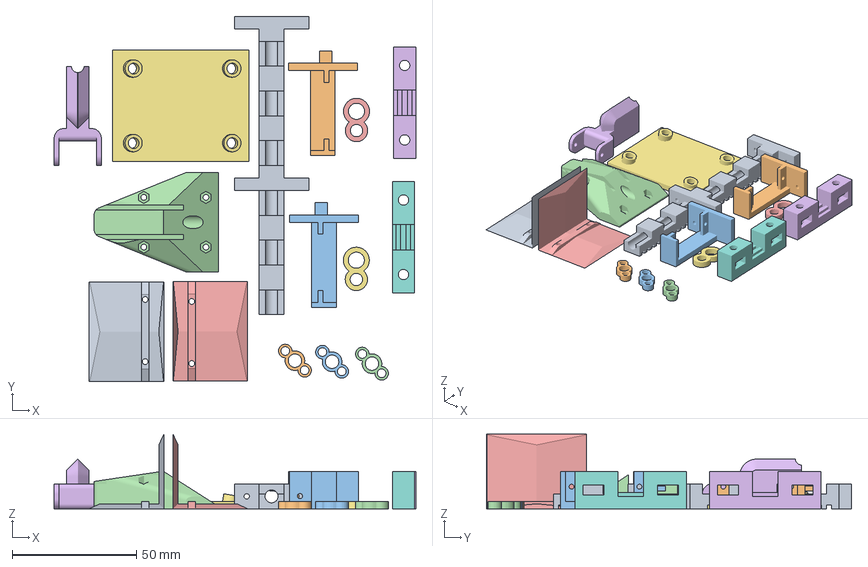
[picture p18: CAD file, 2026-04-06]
CAD/3D Printed Parts/GCODE/PETG_COMPONENTS.3mf
145.6 x 146.9 x 30.0 mm
Mockingbird_V1_Proto-CFTube001.stl
Mockingbird_V1_Proto-ServoMountPort.stl
Mockingbird_V1_Proto-ServoMountStarboard.stl
Mockingbird_V1_Proto-TailfinAdapter.stl
Mockingbird_V1_Proto-TailfinReinforcement.stl x 2
Mockingbird_V1_Proto-WingHolder.stl x 2
WingClamp-WingClamp.stl
WireGuide.stl x 3
CameraCableGuide.stl x 2
CameraMount.stl

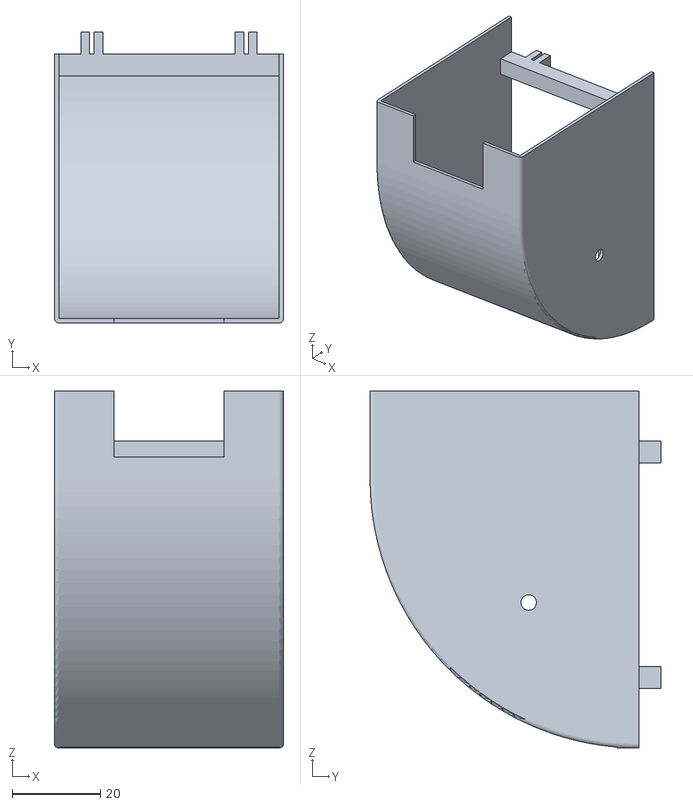
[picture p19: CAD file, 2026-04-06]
CAD/3D Printed Parts/STL/RearFairing.stl
52.0 x 66.0 x 81.0

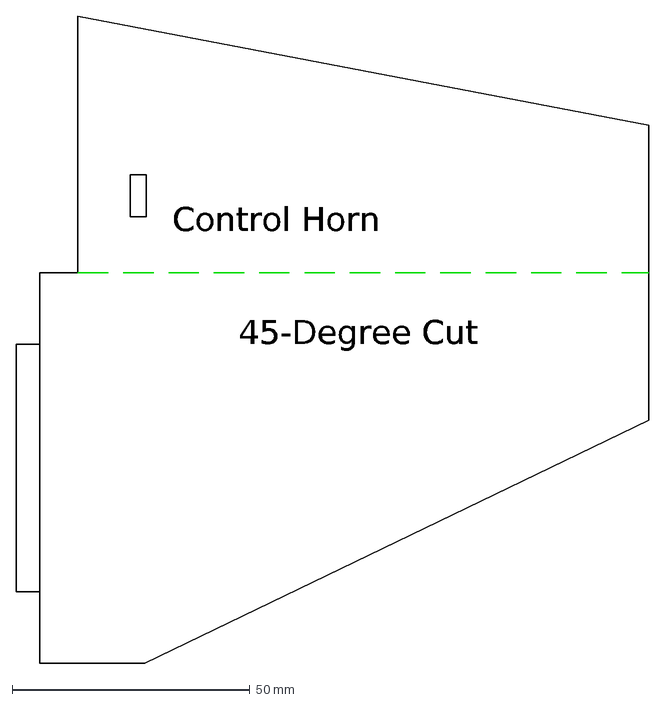
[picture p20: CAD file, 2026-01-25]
CAD/Foam Templates/DXF/VerticalStabilizerTemplate.dxf
Control Horn
45-Degree Cut

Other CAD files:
CAD/Foam Templates/FreeCAD Source/TailfinAssembly.FCStd
CAD/Foam Templates/FreeCAD Source/ArminWing.FCStd
Utilities/Servo-SG90.stl
CAD/3D Printed Parts/FreeCAD Source Files/WingClamp.FCStd
CAD/3D Printed Parts/FreeCAD Source Files/ControlHorns.FCStd
CAD/3D Printed Parts/GCODE/CONTROL.3mf
CAD/3D Printed Parts/GCODE/FRONT_FAIRING.3mf
CAD/3D Printed Parts/GCODE/MOTOR_MOUNT.3mf
CAD/3D Printed Parts/GCODE/SERVO_FAIRINGS.3mf
CAD/3D Printed Parts/GCODE/TOP_FAIRING.3mf
CAD/3D Printed Parts/GCODE/VTX_MOUNT.3mf
CAD/3D Printed Parts/STL/CameraCableGuide.stl
CAD/3D Printed Parts/STL/CameraMount.stl
CAD/3D Printed Parts/STL/ControlHorn.stl
CAD/3D Printed Parts/STL/ControlHornTab.stl
CAD/3D Printed Parts/STL/FrontFairing.stl
CAD/3D Printed Parts/STL/MotorMount.stl
CAD/3D Printed Parts/STL/ServoFairing-Left.stl
CAD/3D Printed Parts/STL/ServoFairing-Right.stl
CAD/3D Printed Parts/STL/ServoMountLeft.stl
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

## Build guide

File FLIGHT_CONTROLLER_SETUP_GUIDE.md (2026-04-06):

# Flight Controller Setup Guide: SpeedyBee F405 Wing Mini (INAV)

This guide covers the installation and configuration of the SpeedyBee F405 Wing Mini with the following hardware:
- **VTX:** AKK Race Ranger
- **Camera:** CADDX FPV Ant
- **GPS:** BN-880 (with Compass)
- **Receiver:** Radiomaster ELRS-RP3-V2
- **Radio:** Radiomaster Pocket
- **Goggles:** Eachine EV800D

---

## 1. Wiring & Custom Cables

### **A. GPS & Compass (BN-880)**
The BN-880 and the SpeedyBee F405 Wing Mini both use 6-pin SH1.0 connectors, but the **pinouts are different**. You must repin the cable or solder directly to the pads.

| BN-880 Pin | Function | FC Pad (Front) | FC Connector (Back) |
| :--- | :--- | :--- | :--- |
| 1 | SDA | SDA | Pin 1 (SDA) |
| 2 | GND | G | Pin 4 (G) |
| 3 | TX | RX3 | Pin 5 (RX3) |
| 4 | RX | TX3 | Pin 6 (TX3) |
| 5 | VCC (5V) | 4V5 | Pin 3 (V) |
| 6 | SCL | SCL | Pin 2 (SCL) |

**Note:** Connecting to `4V5` instead of `5V` or `V` allows the GPS and Receiver to be powered by the USB cable during configuration.

### **B. Servo Power & ESC Connection**
The SpeedyBee F405 Wing Mini has a unique power layout. By default, the servo pins (**Vx**) have **NO POWER**, even when a battery is plugged in.

1.  **Activate Servo BEC:** You MUST solder the two pads of the **"Servo BEC Power Supply Jumper"** on the **back of the PDB board** shut. This connects the internal 4.5A BEC to the servo rail.
2.  **ESC Wiring (S1):** For safety and reliability, use the FC's internal BEC to power servos, not the ESC's.
    *   **Depin Red Wire:** Use a small needle to lift the plastic tab on the ESC's 3-wire connector and pull the **Red (5V)** wire out. Wrap it in electrical tape.
    *   **Connect to S1:** Plug the ESC (now with only Signal and Ground) into the **S1** pins.
3.  **Servo Connections:** Plug your servos into **S2 (Roll), S3 (Pitch), and S4 (Yaw)**.

### **C. VTX & Camera (AKK Race Ranger & CADDX Ant)**
To ensure clean video, we will power the camera from the VTX's filtered 5V output.

1.  **VTX to FC:**
    - **7-26V In** -> **Vv** (Ensure the VTX Power Jumper on the PDB is set to **BAT** for 2S-6S).
    - **GND** -> **G**
    - **Video** -> **Vi** (Video Output from FC OSD)
    - **Smart Audio** -> **T5** (UART5 TX)
2.  **Camera to VTX/FC:**
    - **VCC** -> **AKK 5V Output**
    - **GND** -> **AKK GND**
    - **Video** -> **C1** (Video Input to FC OSD)

### **C. Receiver (Radiomaster RP3-V2)**
The RP3-V2 uses UART1.

- **5V** -> **4V5** (Powers RX via USB)
- **GND** -> **G**
- **TX** -> **RX1**
- **RX** -> **TX1**

---

## 2. Software Setup (INAV)

### **Linux-Specific Preparation**
If you are using Linux, you must grant permissions for your user to access the STM32 bootloader (DFU mode) and serial ports.

1.  **Create udev rule for DFU mode:**
    ```bash
    echo 'SUBSYSTEM=="usb", ATTRS{idVendor}=="0483", ATTRS{idProduct}=="df11", MODE="0664", GROUP="plugdev"' | sudo tee /etc/udev/rules.d/45-stdfu.rules
    ```
2.  **Add your user to necessary groups:**
    ```bash
    sudo usermod -aG dialout,plugdev $USER
    ```
3.  **Reload rules:**
    ```bash
    sudo udevadm control --reload-rules && sudo udevadm trigger
    ```
*Note: You may need to log out and back in for group changes to take effect.*

### **Step 1: Flashing Firmware**
1.  Download and open the **INAV Configurator**.
2.  Connect the FC to your PC via USB while holding the **BOOT** button.
3.  In the "Firmware Flasher" tab:
    - Select Target: `SPEEDYBEEF405WING`.
    - Select the latest stable version.
    - Click **Load Firmware [Online]** then **Flash Firmware**.

### **Step 2: IMU Calibration**
1.  Connect to the FC.
2.  Go to the **Calibration** tab.
3.  Place the aircraft on a level surface and follow the 6-step calibration process for the Accelerometer.

### **Step 3: Ports Configuration**
In the **Ports** tab, set the following and click **Save and Reboot**:
- **UART1:** Serial RX (for ELRS).
- **UART3:** GPS.
- **UART5:** Peripherals -> **TBS SmartAudio**.

### **Step 4: Configuration Tab**
- **Board Alignment:**
    - Due to the narrow profile of the Pod, the FC is often mounted on its side.
    - **Roll Degrees:** `-90`
    - **Yaw Degrees:** `180`
    - **Verification:** In the **Setup** tab, the 3D model must move exactly like the physical aircraft.
- **Receiver:**
    - Receiver Mode: **Serial-based receiver**.
    - Serial Receiver Provider: **CRSF**.
- **GPS:**
    - Enable **GPS for navigation and telemetry**.
    - Protocol: **UBLOX**.
    - Ground Assistance: **Auto**.
- **Compass:**
    - Enable **Magnetometer**.
    - Select **HMC5883** (or QMC5883 if not detected).
    - Alignment: Typically `CW 270 Flip` if mounted flat, but check the map orientation.

---

## 3. Testing Procedures

### **Test 1: FPV System**
1.  Attach antennas to the VTX and Goggles (NEVER power VTX without antenna).
2.  Power the FC via battery.
3.  Set your Eachine EV800D to the frequency configured on the AKK Race Ranger.
4.  **Verification:** You should see the CADDX Ant video feed with the INAV OSD overlay.

### **Test 2: GPS & Compass**
1.  Take the aircraft outside or near a window.
2.  In the INAV **GPS** tab, wait for 3D Fix (indicated by Blue LED on BN-880).
3.  **Verification:** You should see your coordinates and at least 6+ satellites. In the **Setup** tab, ensure the 3D model moves correctly when you rotate the plane (Compass check).

### **Test 3: Radio Control (Static Test)**
1.  **Bind:** Power the RP3-V2 on/off 3 times to enter bind mode (Fast green flash). On your Radiomaster Pocket, run the ExpressLRS LUA script and hit **Bind**.
2.  **Verify Channels:** In the **Receiver** tab, move your sticks.
    - Roll -> Channel 1
    - Pitch -> Channel 2
    - Throttle -> Channel 3
    - Yaw -> Channel 4
3.  **Failsafe:** Turn off the radio; ensure the "Failsafe" indicator in INAV turns Red.

---

## 4. Final Checklist Before Flight
- [ ] Check Motor/Servo directions in the **Outputs** tab.
- [ ] Verify Failsafe behavior (Motor cut).
- [ ] Calibrate the Battery Voltage in the **Power & Battery** tab.
- [ ] Set up Modes (Arm, Angle/Horizon, Nav Launch, RTH) on your radio switches.

Absolutely! Here’s a concise **README-style guide** combining everything you need to set up a new **EdgeTX profile** and get your **INAV flight controller** running for a fixed-wing drone like your MKBD F405 Wing Mini:

---

# README: EdgeTX + INAV Setup for Fixed-Wing (MKBD F405 Wing Mini)

## 1. Create a New Model in EdgeTX

1. **Power on** Radiomaster Pocket.
2. Press **MENU → MODEL → Select an empty slot**.
3. Choose **New Model** (or **Copy Model** to clone an old setup).
4. Enter a **model name** (e.g., `MKBD Wing`).
5. Select **Airplane / Wing** as model type.
6. Assign **External Module → Protocol = CRSF** for ELRS receiver.
7. Save the model.

---

## 2. Configure Inputs

| Function | Input / Channel |
| --- | --- |
| Aileron | CH1 |
| Elevator / Elevon | CH2 |
| Throttle / Motor  | CH3 |
| Rudder | CH4 |
| Arm / AUX switch  | CH5 |

* Verify stick movement in **Inputs tab**; bars should move with the stick.
* Adjust **Reverse / Expo** if servo direction or sensitivity is wrong.

---

## 3. Assign Arming Switch

1. Go to **MODEL SETUP → MODES**.
2. Add a **Mode → ARM/DISARM**.
3. Assign your **AUX switch channel** (e.g., CH5) and define the armed range.
4. Press **Save**.
5. Motor will only respond when armed; servos move even when disarmed.

---

## 4. Map Motor Output in INAV

1. Go to **Configuration → Resource / Pin Assignments**.
2. Assign **Motor 1** to the pin connected to your ESC (typically **S1**).
3. Disable **Motor Stop** for immediate response.
4. In **Mixer tab**, add:

| Output  | Source | Scale |
| --- | --- | ----- |
| Motor 1 | THR | 100%  |

5. Save and reboot the FC.

---

## 5. Configure Servo Outputs

| FC Pin | Function |
| --- | --- |
| S2 | Left Aileron |
| S3 | Right Aileron (reverse if needed) |
| S4 | Elevator |
| S5 | Rudder |

* In **Mixer tab**, assign outputs to sources: AIL, AIL2, ELE, RUD.
* Enable **Reverse** for any servo moving opposite direction of stick input.

---

## 6. Bind ELRS Receiver

1. Put receiver in **bind mode**.
2. In EdgeTX: **MODEL SETUP → EXTERNAL MODULE → Bind**.
3. Confirm **Status = ON**, **Baudrate = 500k**, **Receiver = CRSF**.
4. Verify stick movement in **Receiver tab** of INAV.

---

## 7. Testing Checklist (No Propeller)

1. Check **Ailerons** move opposite directions with roll stick.
2. Check **Elevator** moves up/down with pitch stick.
3. Check **Rudder** moves left/right with yaw stick.
4. Arm the FC using your **arm switch** (CH5).
5. Slowly move **Throttle**; Motor 1 bar should respond.

---

## 8. Tips / Troubleshooting

* **Throttle input moves in Receiver tab but Motor bar doesn’t** → check Motor 1 pin assignment & mixer.
* **Servo moves opposite** → toggle **Reverse** in Mixer tab.
* **No receiver input** → ensure **External Module → CRSF / 500k / Status ON** is set per model.
* Always **remove propeller** when testing motor.

---

This README provides a **step-by-step reference** for creating a working EdgeTX profile and configuring the MKBD F405 Wing Mini in INAV.

---

If you want, I can make a **diagram showing the full FC pinout with motor and control surfaces, plus channel mapping from EdgeTX**, which makes this README visual and easier to follow.

Do you want me to make that diagram?

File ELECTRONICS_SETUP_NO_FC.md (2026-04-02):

# Electronics Setup

## Plugging Everything In

TODO: add pictures
TODO: explain what channel connects to what
TODO: tell the user to label setuff

## Radiomaster Setup

### 1. Enabling Internal RF (Fixes LUA "Loading" Hang)
The Radiomaster Pocket must have its internal module powered and set to the correct protocol to communicate with ELRS.
1.  Press the **[MDL]** button.
2.  Press **[PAGE >]** once to reach the **SETUP** page.
3.  Scroll down to **Internal RF**.
4.  Set **Mode** to **CRSF** (this enables the ELRS module).
5.  Ensure **External RF** is set to **OFF**.

### 2. Binding ELRS

#### Traditional Method (No Binding Phrase)
1. Power the receiver on and off three times consecutively (with roughly 2-second intervals).
2. The LED should start blinking twice in a cycle, indicating it is in binding mode.
3. Open the ExpressLRS LUA script on your transmitter ([SYS] -> ExpressLRS) and select the **[Bind]** option.
4. The receiver LED will turn solid when successfully paired.

#### Binding Phrase Method (Recommended via Wi-Fi)
This method allows you to "lock" your radio to your receiver without manual binding. You must set the **same phrase** on both.

**A. Configure the Radio (Transmitter):**
1.  Open the **ExpressLRS** LUA script on your radio ([SYS] -> ExpressLRS).
2.  Select **[WiFi Enable]**.
3.  On your PC/Phone, connect to the Wi-Fi network: `ExpressLRS TX` (Password: `expresslrs`).
4.  Open a browser to `http://10.0.0.1`.
5.  Enter your custom **Binding Phrase** and click **Save**.

**B. Configure the Receiver (RP3-V2):**
1.  **Power On:** Plug in the drone's battery or connect the flight controller to your PC via USB (if the receiver is powered by the FC's USB).
2.  **Wait for Wi-Fi Mode:** Wait exactly **60 seconds** without turning on your radio.
    *   The LED will first blink slowly (searching for radio).
    *   After 60 seconds, the LED will start **flashing rapidly**, indicating it is now in Wi-Fi mode.
3.  **Connect:** On your phone or PC, look for the Wi-Fi network: `ExpressLRS RX` (Password: `expresslrs`).
4.  **Configure:** Open your browser and go to `http://10.0.0.1`.
5.  **Save Phrase:** Type the **exact same Binding Phrase** used on the radio into the text box and click **Save & Reboot**.

**C. Result:**
Once both devices reboot, they will instantly pair (LED will turn **Solid Green**) as long as they share the same phrase.

## PWM Control Pin Layout (INAV)

For the **SpeedyBee F405 Wing Mini** using the standard Airplane mixer, connect your components to the following pins:

| Pin Label | INAV Mixer | Control Axis | Component |
| :--- | :--- | :--- | :--- |
| **S1** | Motor 1 | Throttle | ESC Signal Wire |
| **S2** | Servo 1 | Roll | Left Aileron Servo |
| **S3** | Servo 2 | Pitch | Elevator Servo |
| **S4** | Servo 3 | Yaw | Rudder Servo |
| **S5** | Servo 4 | Roll | Right Aileron Servo (Optional) |

**Note on Power:** Servos are powered by the built-in BEC. Ensure the **Servo Power Jumper** on the PDB board is bridged for the desired voltage (5V for standard servos, 6V for high-torque).

## Calibrating Motor

1. **Preparation:** Connect the BLDC motor to the ESC. Connect the ESC signal wire to your receiver (usually Channel 3) or servo tester.
2. **Maximum Throttle:** Turn on the transmitter and set the throttle stick to maximum (full up).
3. **Power On:** Plug the battery into the ESC. The motor will beep to indicate it has recognized the maximum throttle position.
4. **Minimum Throttle:** As soon as the beeping stops (or a musical tone is heard), move the throttle stick to the minimum position (full down).
5. **Confirmation:** The ESC will produce a series of beeps indicating the number of battery cells, followed by a long beep, confirming successful calibration.
6. **Finalize:** Unplug the battery, then plug it back in. The ESC is now calibrated and ready to use. 

## Radiomaster Setup

TODO: ADD PICTURES

---
  Radiomaster Pocket Button Layout

  [PAGE <]  [PAGE >]      ← Top shoulder buttons

           [SPEAKER]
  [SYS]               [MDL]    ← Side buttons

      [SCROLL WHEEL]           ← Press to select, rotate to navigate

  [RTN]                        ← Bottom left, goes back/exits

  ---
  Step 1: Create a New Model

  1. Press MDL button (right side of speaker)
  2. You'll see a list of model slots (some empty, some with names)
  3. Rotate scroll wheel to highlight an empty slot
  4. Press scroll wheel to open submenu
  5. Select Create Model → press scroll wheel to confirm
  6. A new model is created and you're now in its settings

  ---
  Step 2: Name Your Model

  1. After creating, press PAGE > once to reach the Setup menu
  2. First option is Model Name - it will show a default name like "Model01"
  3. Press scroll wheel to enter edit mode
  4. You're now in the character editor:
    - Rotate scroll wheel to change the current character (cycles through A-Z, a-z, 0-9, symbols)
    - Press scroll wheel to confirm that character and move to the next position
    - Repeat for each character
  5. When done, press RTN to save the name and exit editor

  ---
  Step 3: Configure Internal RF Module

  Still in the Setup menu:

  1. Rotate scroll wheel down to find Internal RF
  2. Press scroll wheel to edit
  3. Set Mode to CRSF (this enables ELRS)
  4. Press RTN to exit
  5. Scroll down to verify Receiver shows a number (receiver ID)

  ---
  Step 4: Set Up Channels (Method A: Wizard - Easiest)

  1. Press RTN to go back to home screen
  2. Press SYS button (left side of speaker)
  3. You're in the Tools menu
  4. Rotate scroll wheel to find Wizard Loader
  5. Press scroll wheel to open it
  6. Select Multi (for quadcopter/drone)
  7. Follow the prompts:
  ┌──────────────────┬────────────────────────────────────────────────────────────────────┐
  │      Prompt      │                             What to do                             │
  ├──────────────────┼────────────────────────────────────────────────────────────────────┤
  │ Throttle Channel │ Leave as CH3, press scroll wheel                                   │
  ├──────────────────┼────────────────────────────────────────────────────────────────────┤
  │ Roll Channel     │ Leave as CH1, press scroll wheel                                   │
  ├──────────────────┼────────────────────────────────────────────────────────────────────┤
  │ Pitch Channel    │ Leave as CH2, press scroll wheel                                   │
  ├──────────────────┼────────────────────────────────────────────────────────────────────┤
  │ Yaw Channel      │ Leave as CH4, press scroll wheel                                   │
  ├──────────────────┼────────────────────────────────────────────────────────────────────┤
  │ Arm Switch       │ Select SA (2-position switch on left shoulder), press scroll wheel │
  ├──────────────────┼────────────────────────────────────────────────────────────────────┤
  │ Mode Switch      │ Select SB (3-position switch), press scroll wheel                  │
  ├──────────────────┼────────────────────────────────────────────────────────────────────┤
  │ Beeper Switch    │ Select SC or SD, press scroll wheel                                │
  └──────────────────┴────────────────────────────────────────────────────────────────────┘
  8. On confirmation screen, long-press scroll wheel to finish
  ---
  Sources:
  - https://www.flitetest.com/articles/creating-a-new-model-on-the-radiomaster-pocket
  - https://oscarliang.com/setup-radiomaster-pocket/

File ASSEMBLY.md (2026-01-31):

# Assembly

This guide will be updated iteratively as I build more copies of the drone and learn more efficient techniques. If at any point something is unclear, feel free to open an issue in the repo. You can also reference the raw CAD file to see how things fit together.

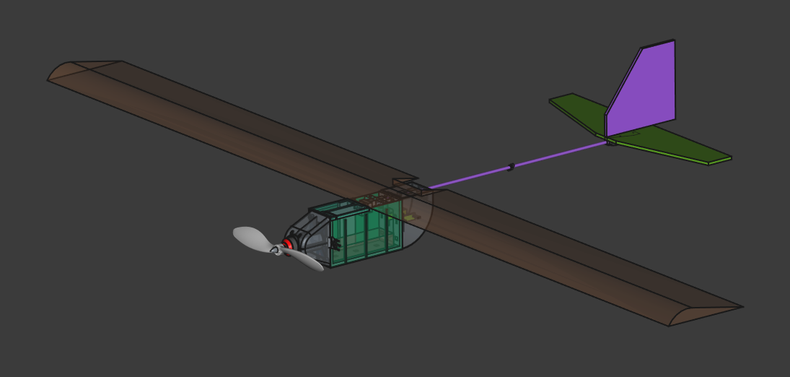
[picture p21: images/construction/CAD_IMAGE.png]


### Parts List

#### 3D Printed Parts

STL files contained at `./CAD/3D Printed Parts/STL`.  
Ready-to-print `.3mf` files at `./CAD/3D Printed Parts/GCODE`.

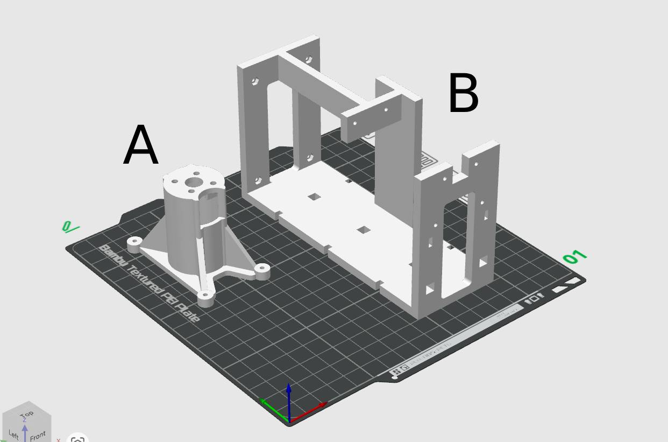
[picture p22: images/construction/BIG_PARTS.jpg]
    

TODO: make the letters in this picture easier to read  
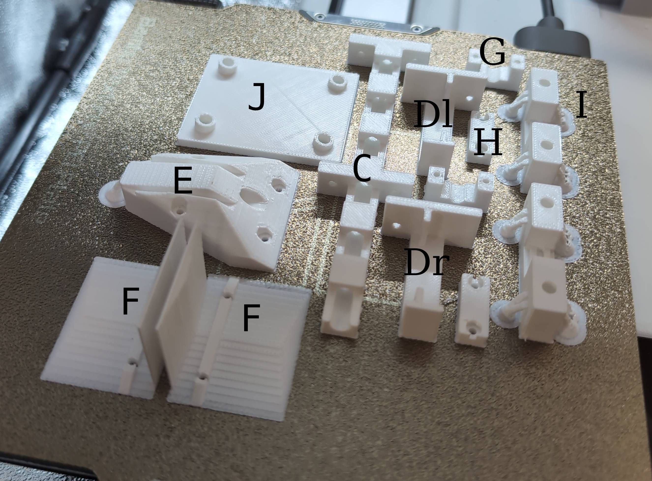
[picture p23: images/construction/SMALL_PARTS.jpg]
    
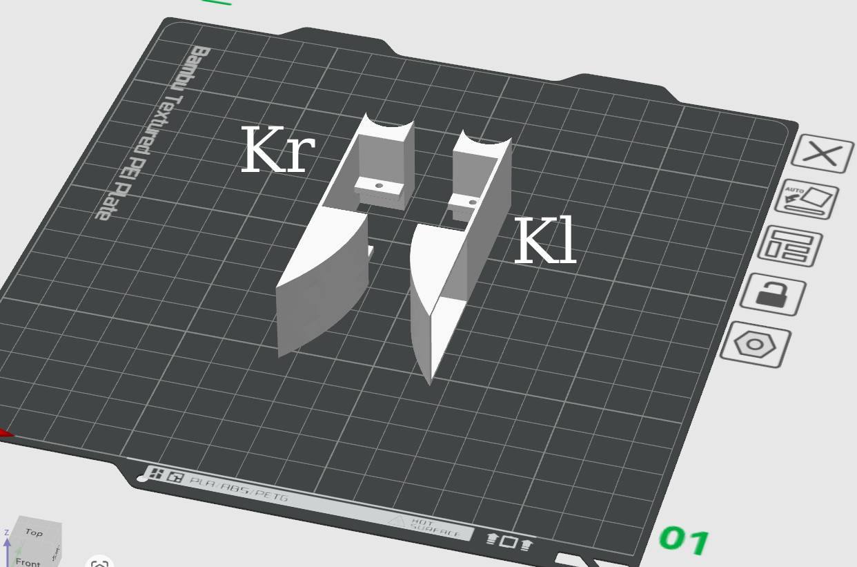
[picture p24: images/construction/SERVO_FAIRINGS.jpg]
    
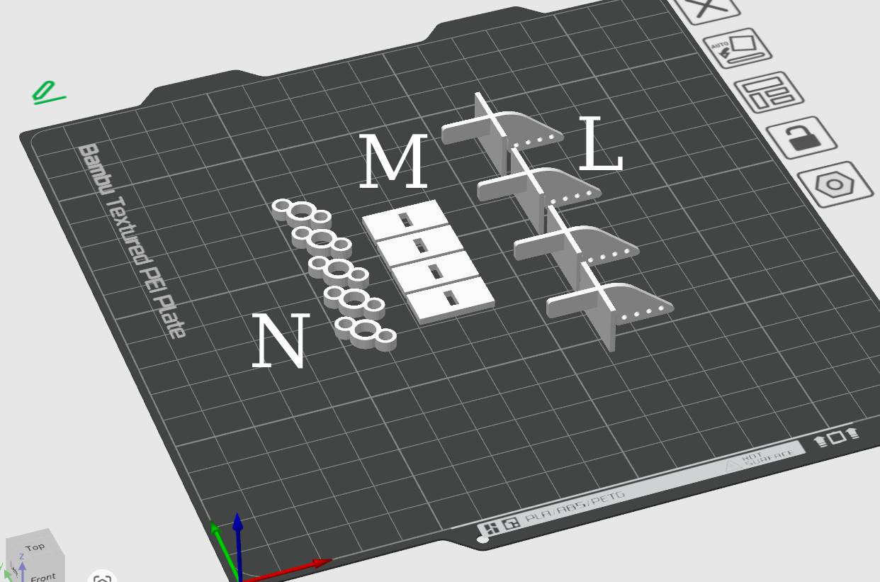
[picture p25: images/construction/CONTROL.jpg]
     

| Letter | Part |
|---|---|
| A | Motor Mount (PETG) |
| B | Pod (PLA) |
| C | Wing Rail (PETG) |
| Dl | Left Servo Mount (PETG) |
| Dr | Right Servo Mount (PETG) |
| E | Tailfin Mount (PETG) |
| F | Tailfin Reinforcements (x2) (PETG) |
| G | Carbon fiber boom clamp (top) (PETG) |
| H | Carbon fiber boom clamp (bottom) (PETG) |
| I | Wing rail screw receiver (PETG) |
| J | Wing screw plate (PETG) |
| Kl | Left wing servo fairing (PLA) |
| Kr | Right wing servo fairing (PLA) |
| L | Control horn (PETG) |
| M | Control horn tab (PETG) |
| N | Pushrod guide (PETG) |

These parts can be printed in anything, but I recommend using PETG for anything that will have significant forces acting on it, as it experiences significantly less [creep](https://en.wikipedia.org/wiki/Creep_(deformation)) than PLA.

To make it easier to cut the foamboard, I recommend 3D printing these cutting jigs.  

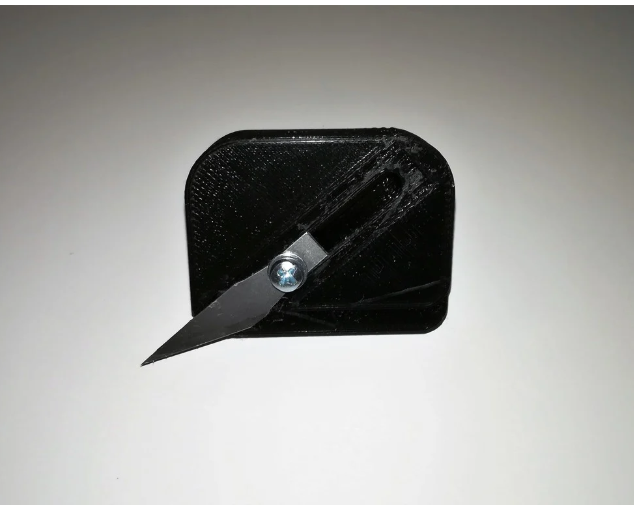
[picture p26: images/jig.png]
    
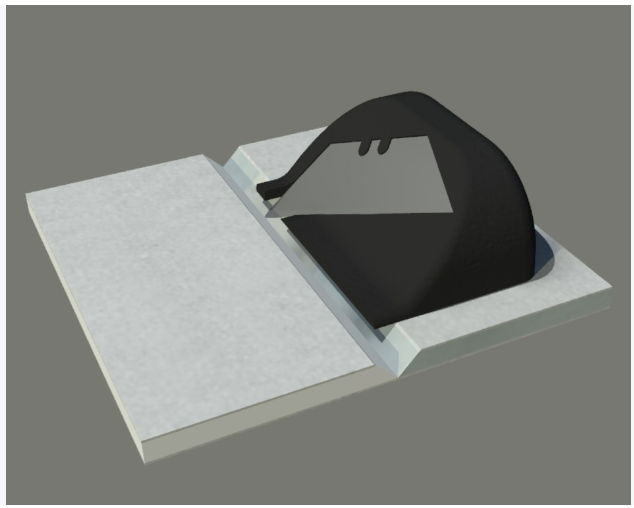
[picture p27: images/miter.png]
    

The files are at `./Utilities/5mmFoamBoardMiterCutter.stl` and `./Utilities/Foam_board_90_degree_cutter.stl`.

#### Fasteners

| Screw | Length | Qty |
|---|---|-----|
| M2 | 8mm | 2 |
| M2 | 10mm | 10  |
| M2 | 16mm | 2 |
| M4 | 30mm | 4 |

#### Other

| Item | Qty |
|---|-----|
| Servo | 4 |
| Motor | 1 |
| Control horns  | 4 |
| 1.2mm Pushrods | 4 |

### Pod Assembly

Motor mount, 2208 motor, screws.  
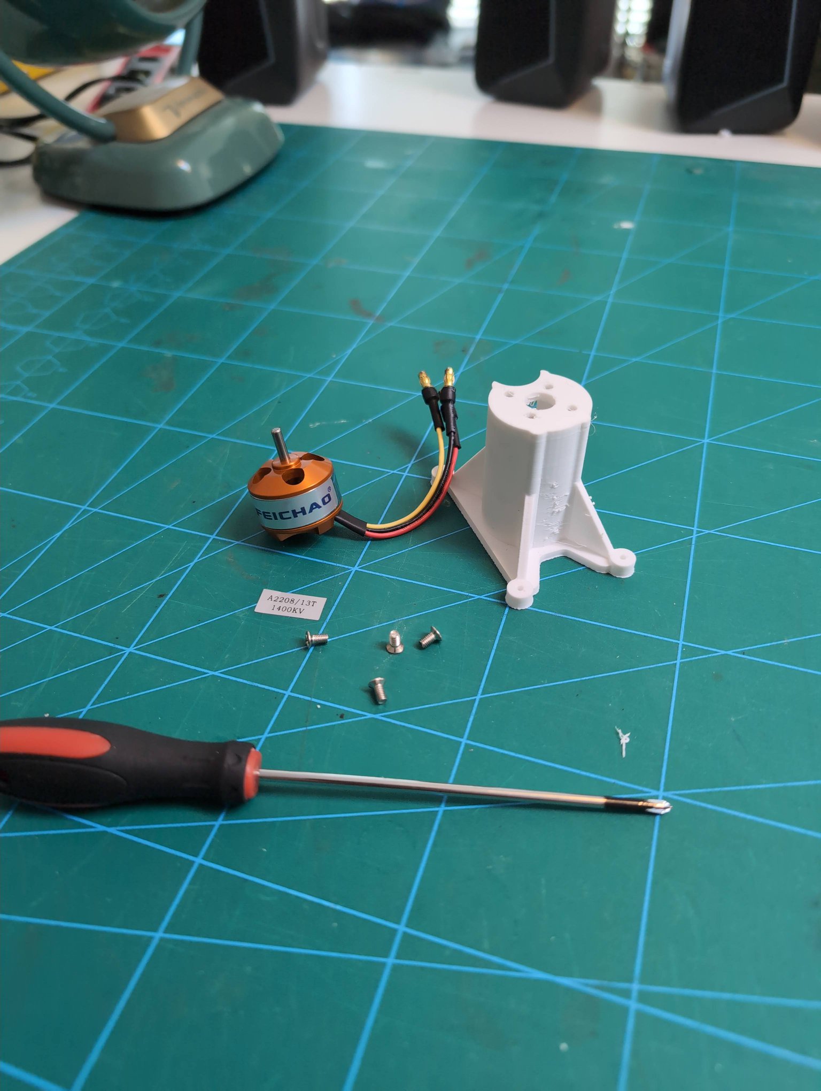
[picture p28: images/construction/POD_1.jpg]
  

Attach the motor to the motor mount.  
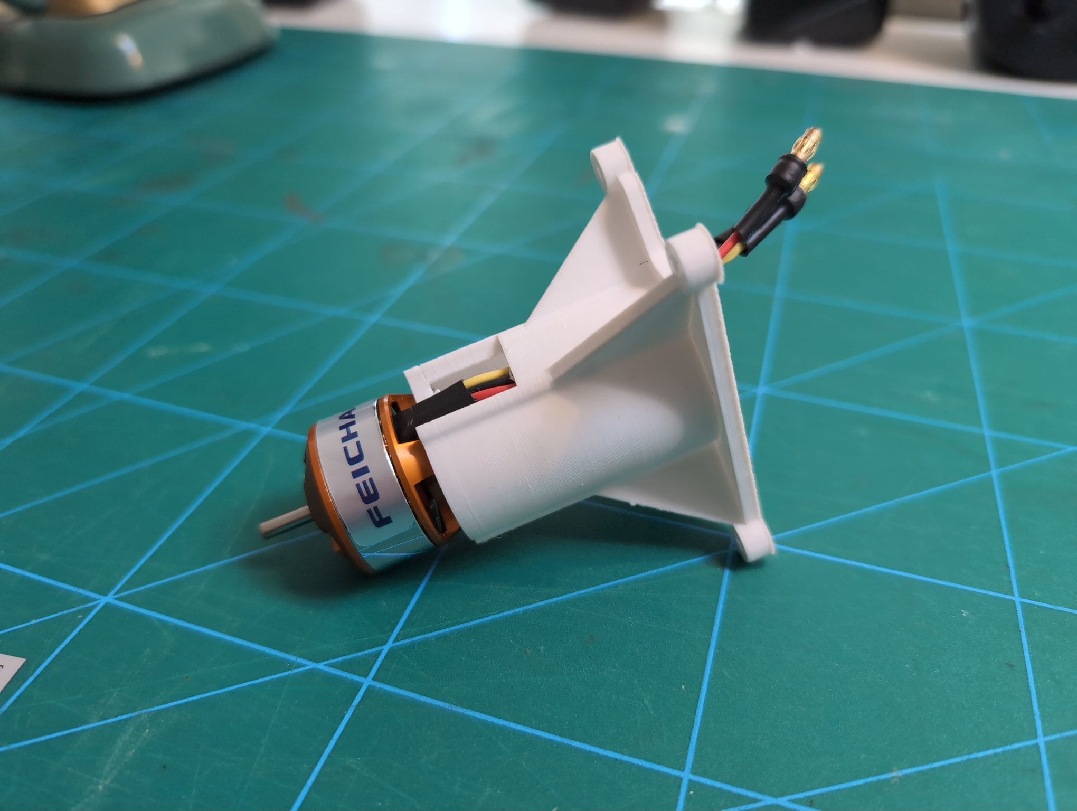
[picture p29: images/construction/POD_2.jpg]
  

Attach the motor mount to the front of the with four 10mm length M2 screws.  
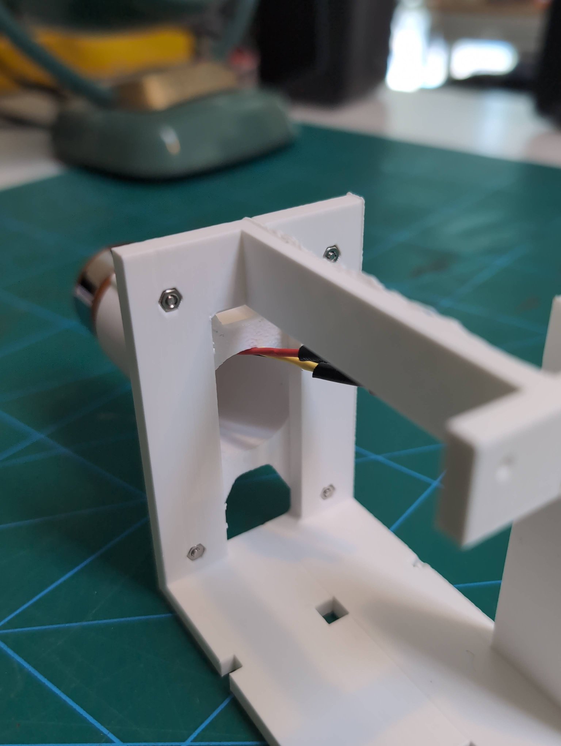
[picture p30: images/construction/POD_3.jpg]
  

Attach the wing mounting rail (printed in PETG) to the pod with four 10mm or 12mm length M2 screws.  
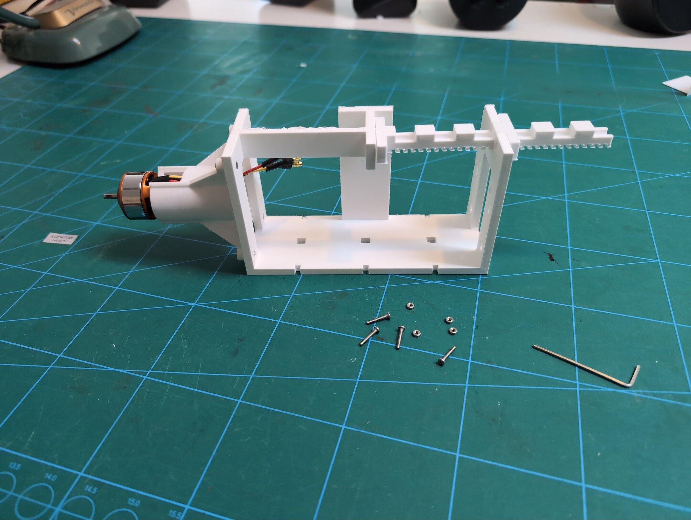
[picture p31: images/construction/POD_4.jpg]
  

Attach the left and right servo mounts using two 8mm or 10mm length M2 screws.  
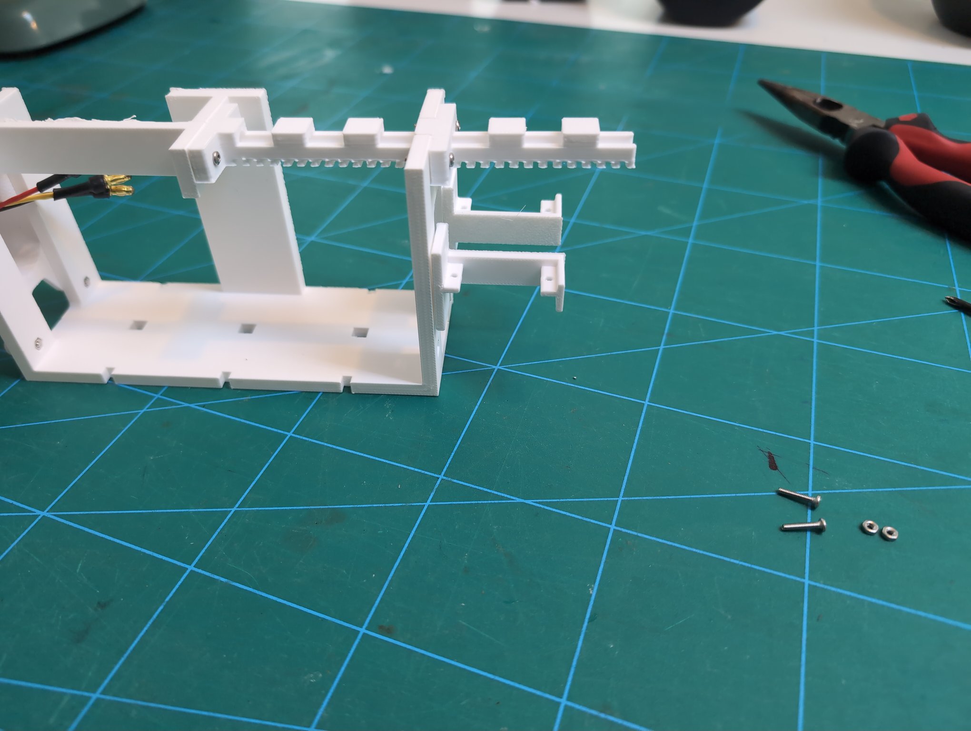
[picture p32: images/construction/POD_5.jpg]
  

Drill a 2mm hole into the third hole of your servo arm.  
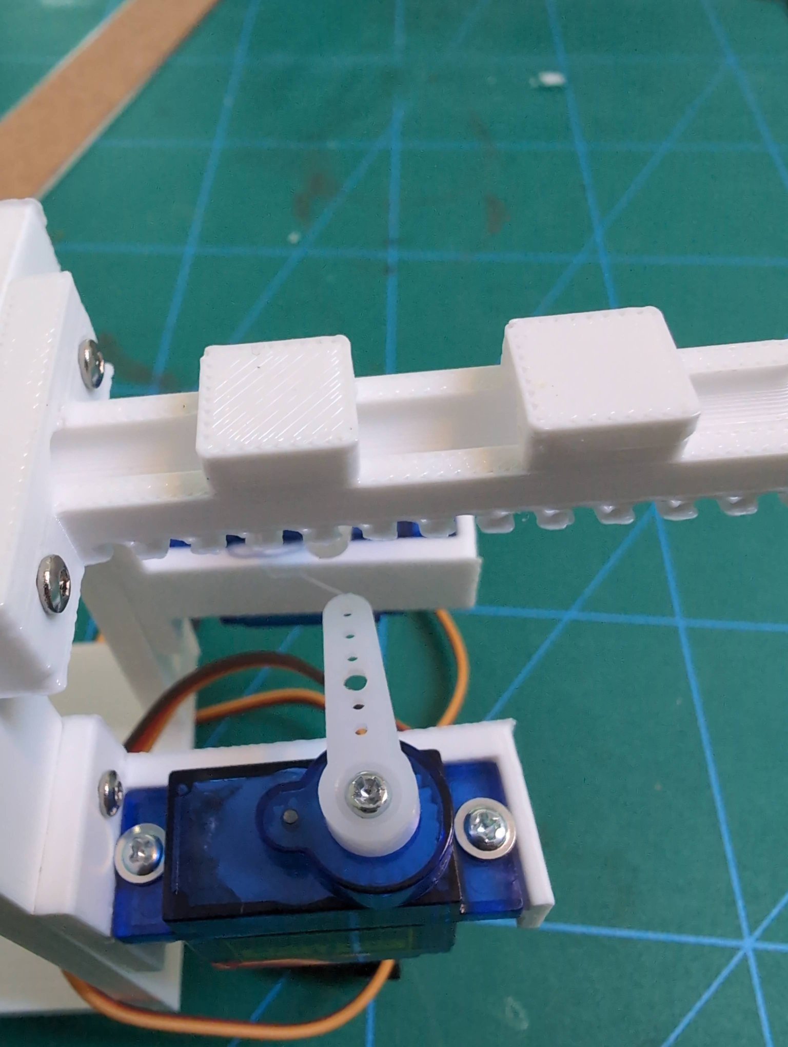
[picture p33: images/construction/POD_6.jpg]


Insert your servos into the mounts with the included mounting screws.  
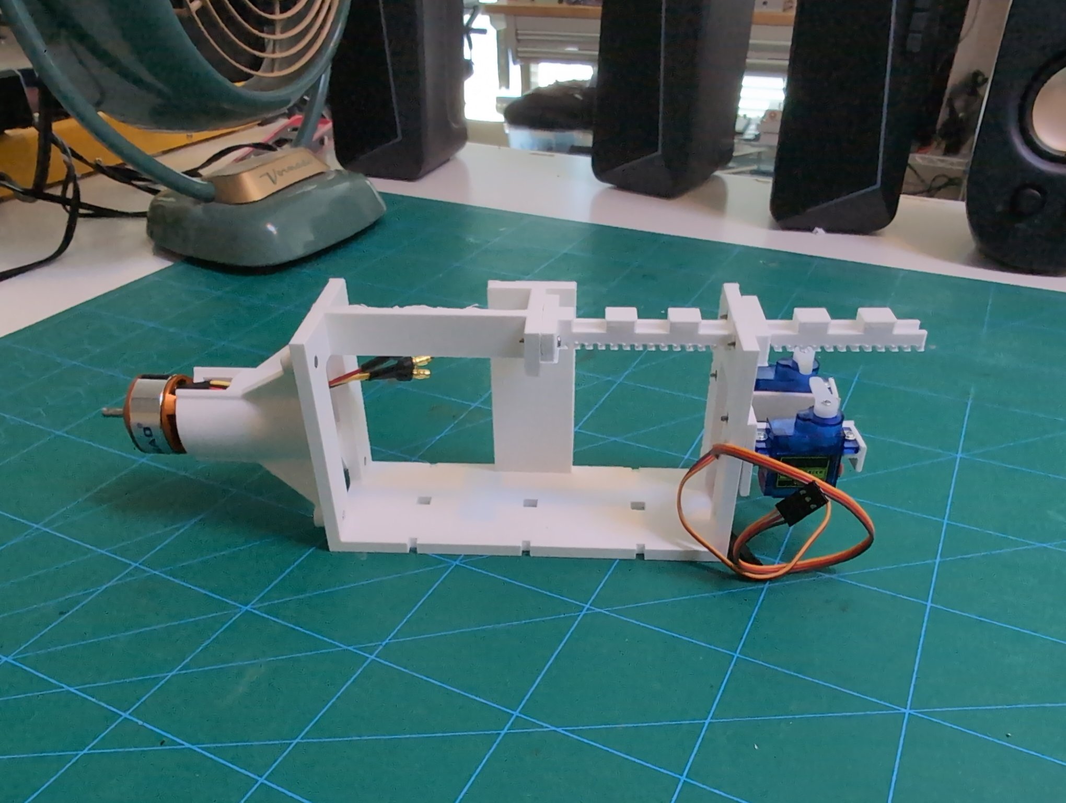
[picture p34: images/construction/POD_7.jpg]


### Tailfin Assembly

PDF templates at `./CAD/Foam Templates/PDF`.  

If you have never cut control surfaces into foamboard, I recommend [this video](https://www.youtube.com/watch?v=e1_pjhQWj98)   

Print out the tailfin templates. The PDF is already sized for 8.5x11" printer paper. Do not rescale the page or apply margins. Tape the pages together and cut out the templates.  
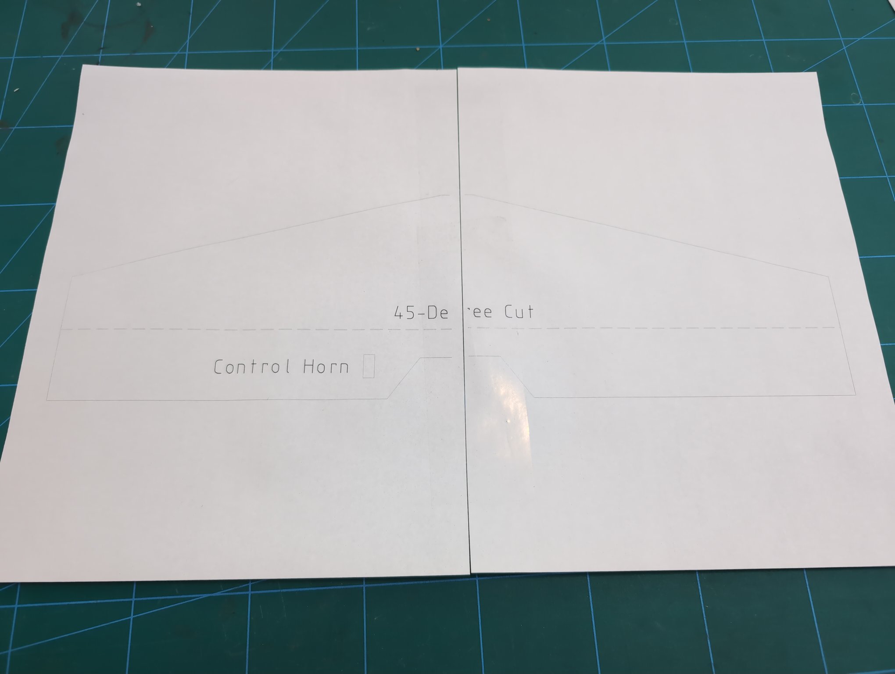
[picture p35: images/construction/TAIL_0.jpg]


Use a ruler to tansfer the outline of the template onto the foamboard. Cut out the foam pieces. Make the half cuts and 45-degree cuts to add control surfaces. Use packing tape to reinforce the bending parts.  
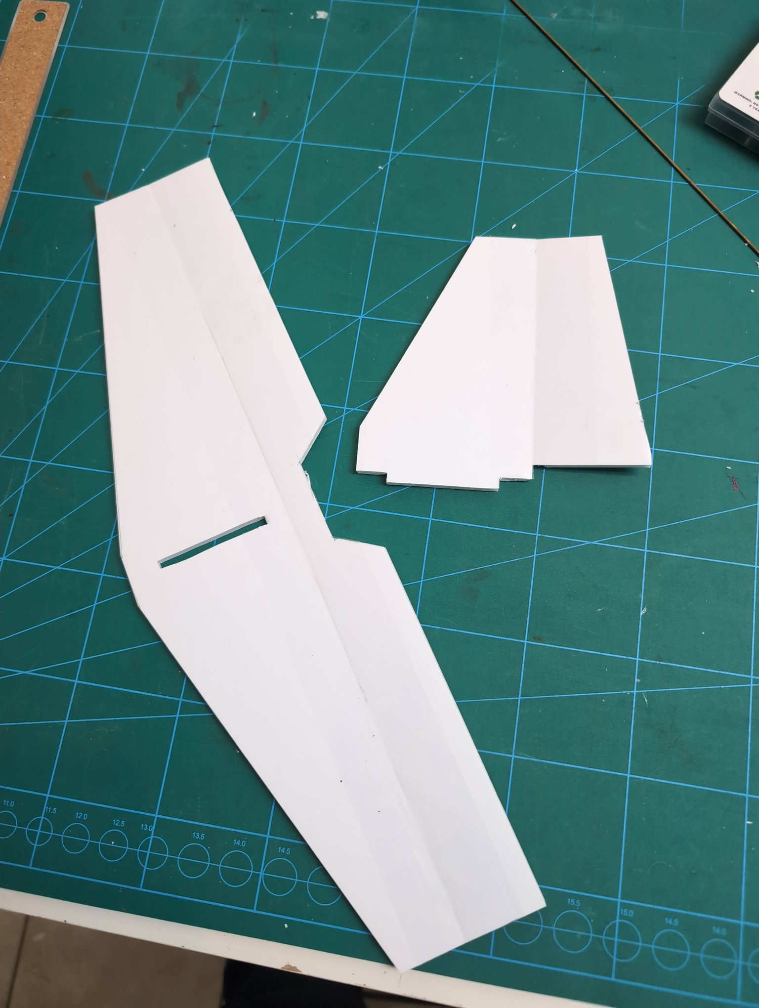
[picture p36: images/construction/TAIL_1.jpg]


Glue the vertical and horizontal stabilizer together.   
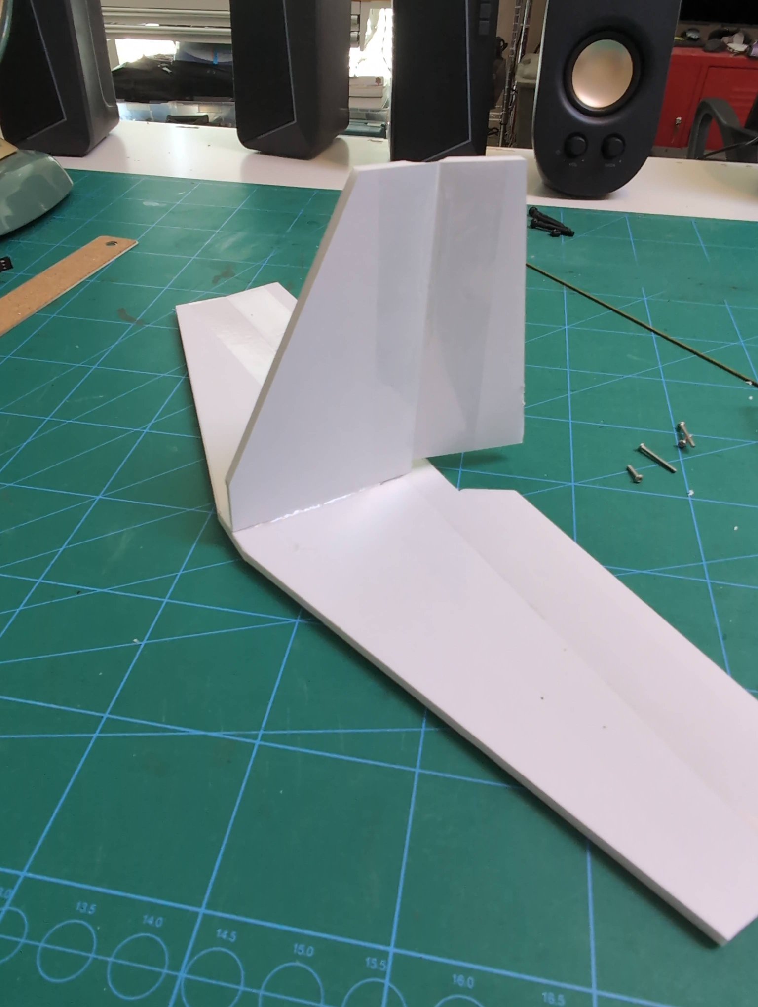
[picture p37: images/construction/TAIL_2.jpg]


Glue the tailfin mount to the underside of the tail fins and use a screwdriver to puncture holes through the horizontal stabilizer. Secure the tailfin reinforcements to the tailfin mount with two 20mm length M2 screws and two 8mm M2 screws. You may optionally glue down the tailfin reinforcements to add extra rigidity to the vertical stabilizer.  
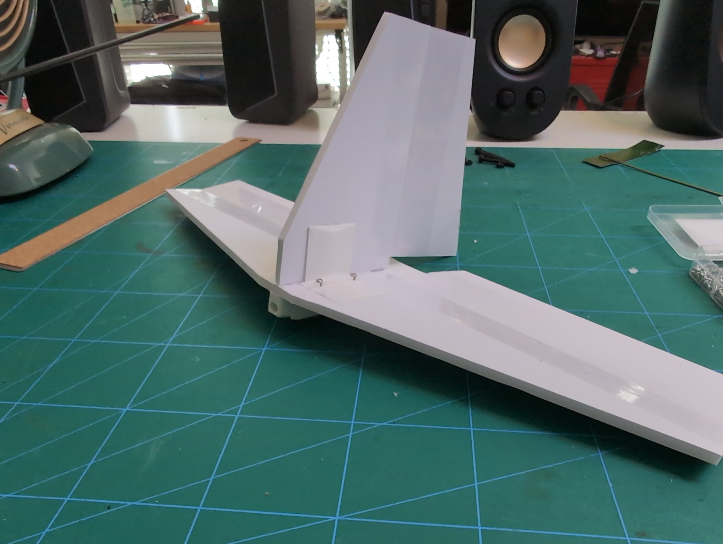
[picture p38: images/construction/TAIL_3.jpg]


TODO: add an image showing how the tailfin mount is glued to the tailfin

### Wing Assembly

TODO: better wing assembly instructions

I would recommend watching [this short video](https://www.youtube.com/watch?v=qJZoqGHAIDE) to understand the basic design of this wing. The wing is attached to the pod with four M4 screws, and can be swapped out for your own custom design. The design I am using is a called an "Armin wing" in the hobbyist community. [Kline-Fogelman](https://en.wikipedia.org/wiki/Kline%E2%80%93Fogleman_airfoil) airfoils may be simpler to build, and should provide a larger wing area for the same quanitity of foamboard.  

Cut out the left and right wing templates and tape them the same way as the tailfin templates. Transfer the templates onto foamboard, and cut them out. One piece of 20"x30" foamboard should yield two wings.  
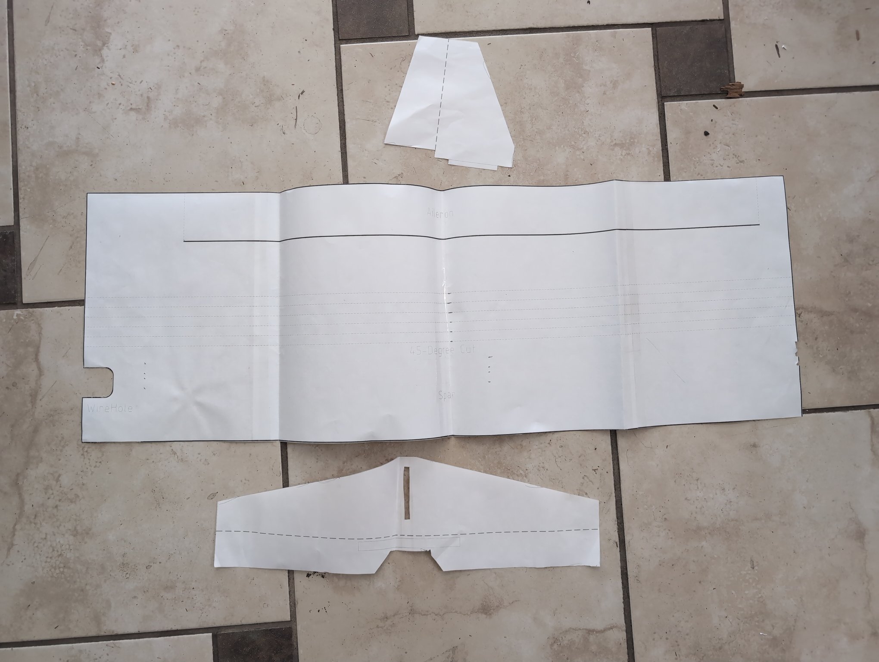
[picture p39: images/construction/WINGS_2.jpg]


Cut each of the blue dashed lines halfway through the foamboard. This will become the leading edge of the wing. Do a 45-degree cut on the dashed line that is labeled.  
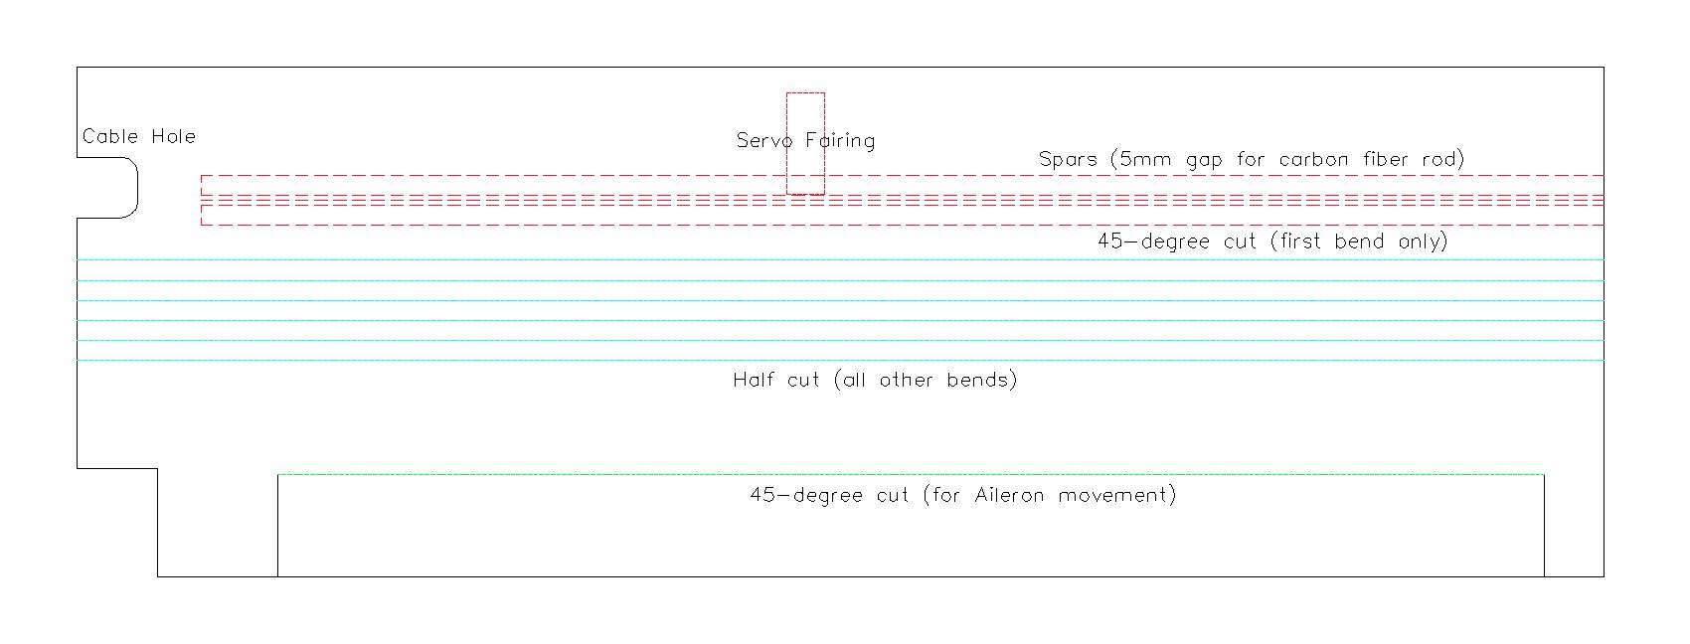
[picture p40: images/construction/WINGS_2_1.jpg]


Here is what the scored section of the wing should look like after cutting.  
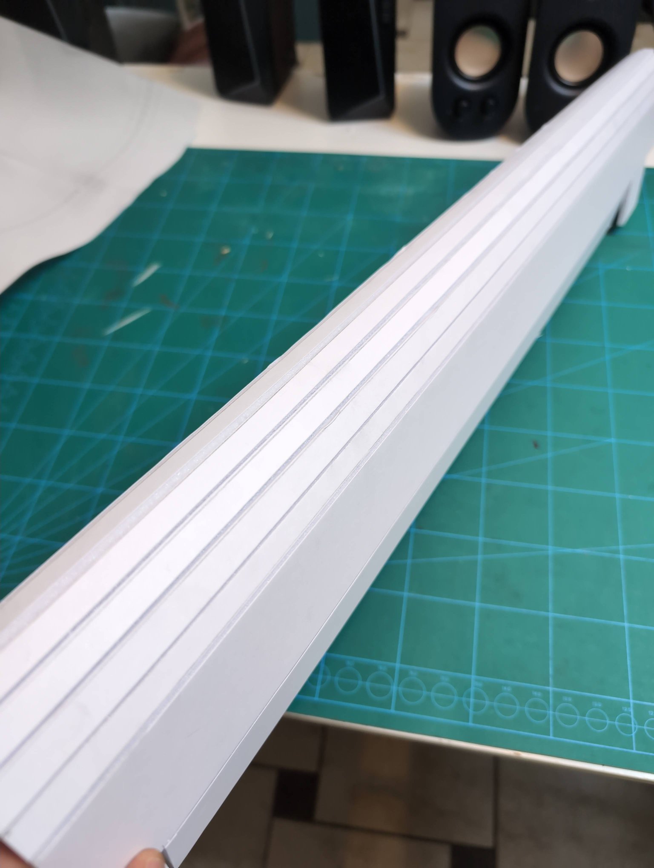
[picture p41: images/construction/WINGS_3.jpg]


Each wing will require three 5mm by 600mm foam spars. There are no templates for these, just cut them out with a ruler. These spars will "sandwich" a removable central carbon fiber spar.  

Example carbon fiber spar placement.  
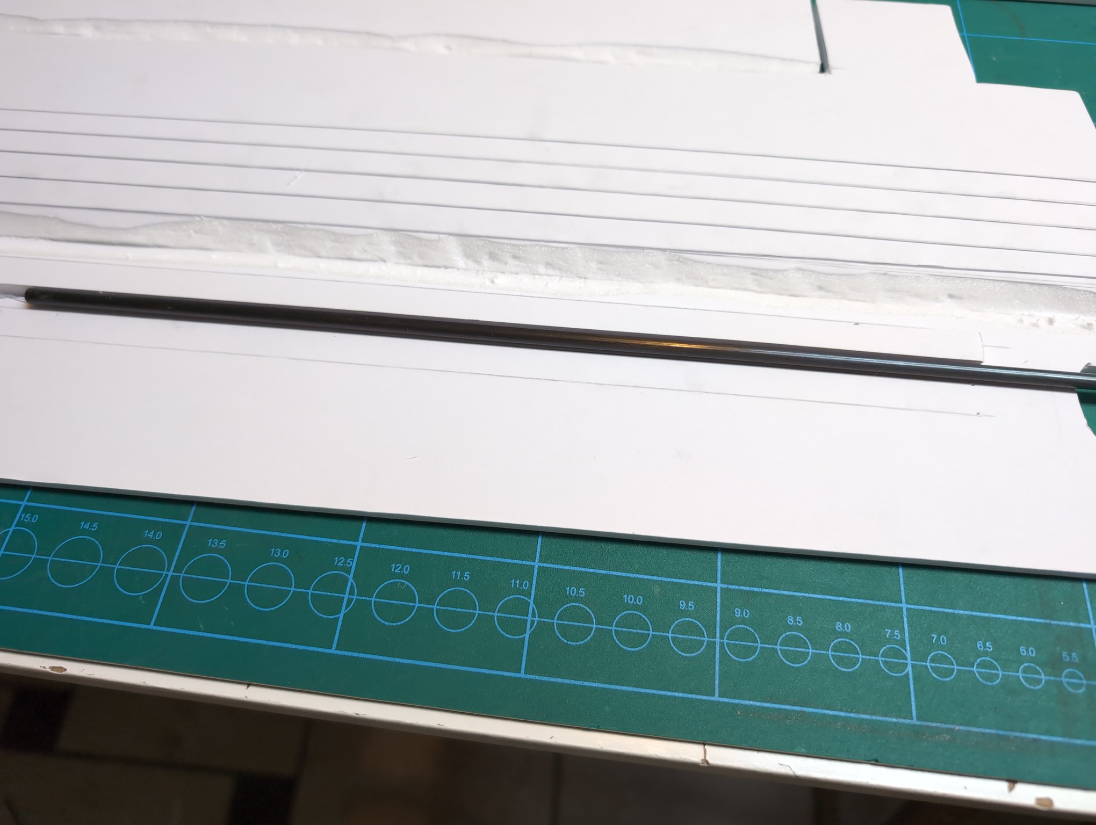
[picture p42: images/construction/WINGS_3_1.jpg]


Pyramid sandwich example.  
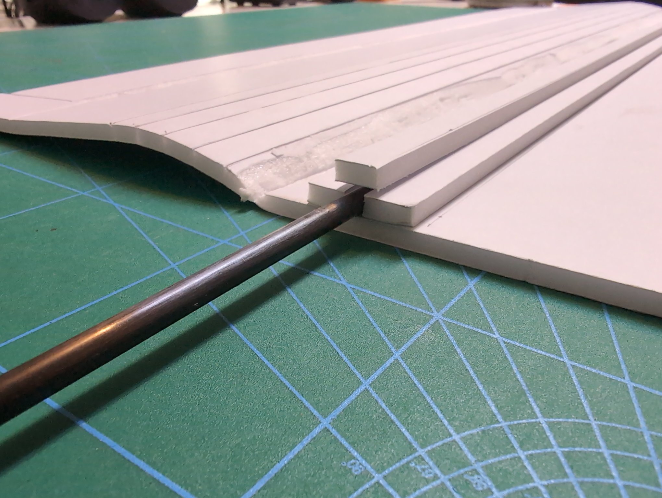
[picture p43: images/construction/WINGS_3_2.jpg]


The folding step is a bit difficult to describe. I recommend watching [this video](https://youtu.be/bllvhjr51Lk?si=4DFRSW2RofPoi4HL&t=564) from timestamps 9:30 to 12:30 if you are a beginner and you struggle to assemble the wing. My wing design is *heavily* inspired by the wing on the Joytrainer Mini, and the construction techniques are identical.

Take the left and right wings, and connect them with the carbon fiber spar. The spar should be half in the left wing and half in the right wing.


Using the Wing Screw Plate as a guide, use a screwdriver to puncture the fully-glued wing with 4 holes.  
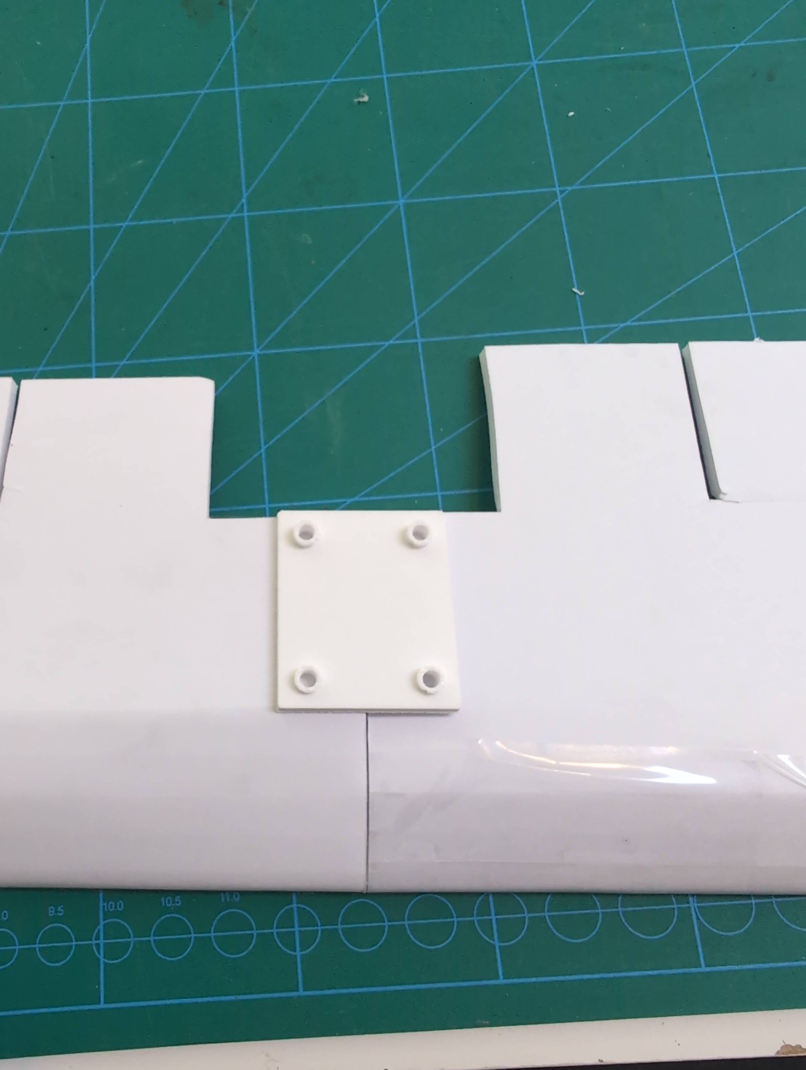
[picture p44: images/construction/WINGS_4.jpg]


Insert four 30mm length M4 screws into the wing.  
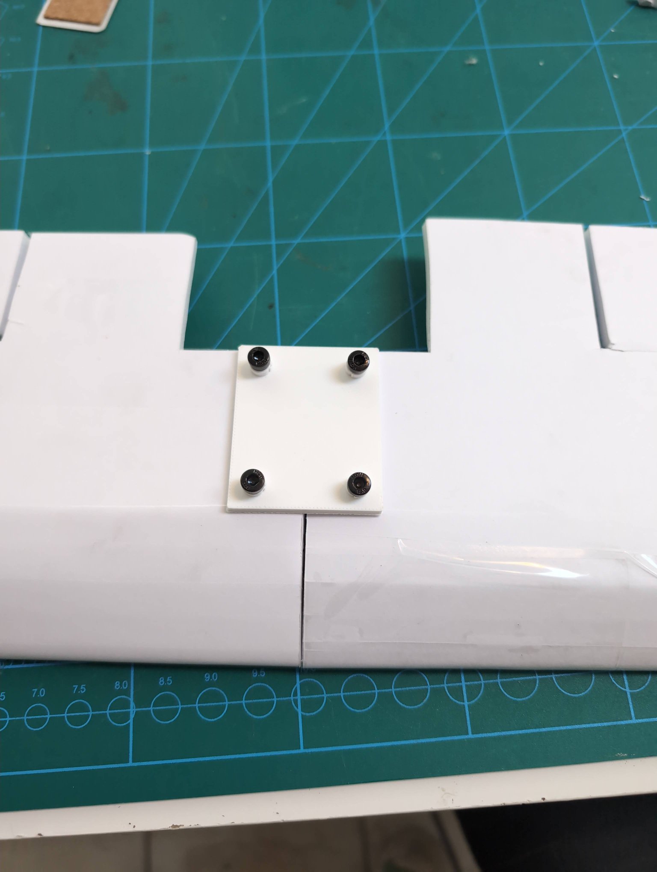
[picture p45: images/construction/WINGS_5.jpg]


Underside view (forgive my terrible quality control)  
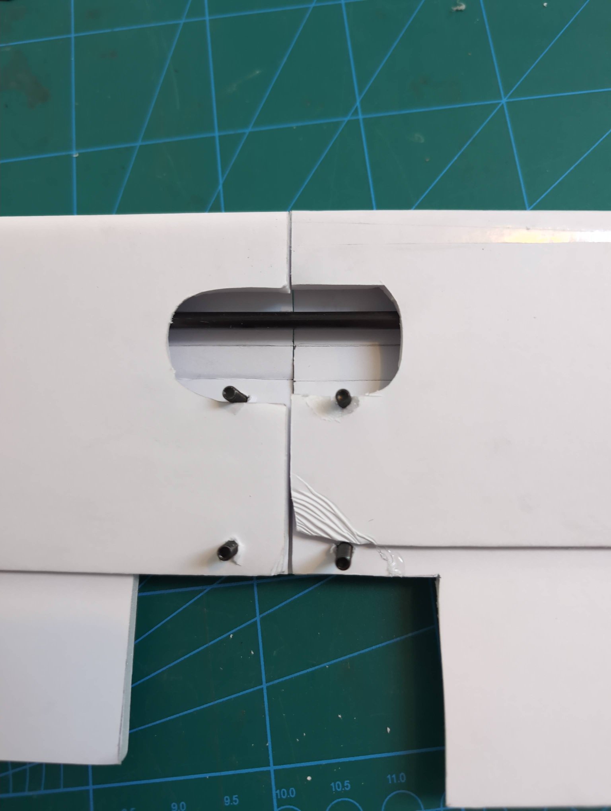
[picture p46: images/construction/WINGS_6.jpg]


Insert your servos into the servo fairings and secure them with screws. 

> You will need to make sure your servos are facing different directions on each wing so that the ailerons move in opposite directions. Corrections are made at the end of this section.    

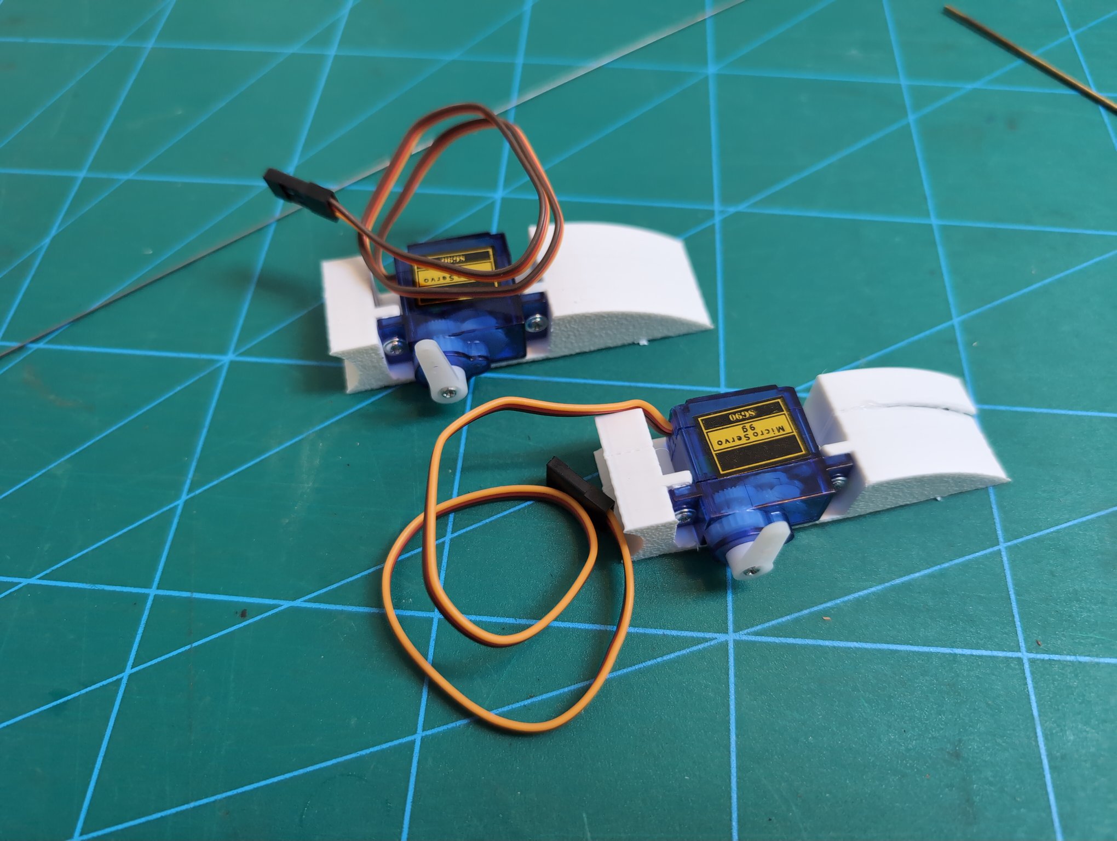
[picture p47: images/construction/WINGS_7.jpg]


Glue your servo fairings and control horns into the area of the wing marked on the template.  
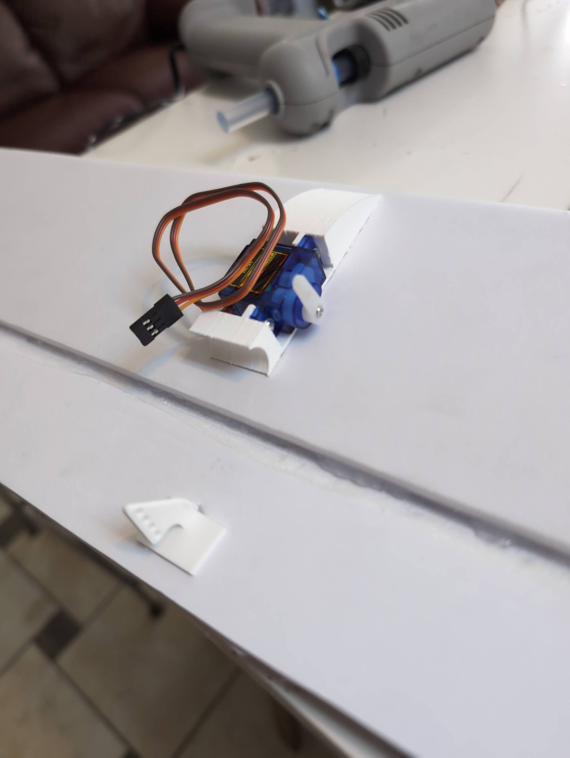
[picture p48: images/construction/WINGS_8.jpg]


Make sure your control horns are held in place with a tab on the other side.  
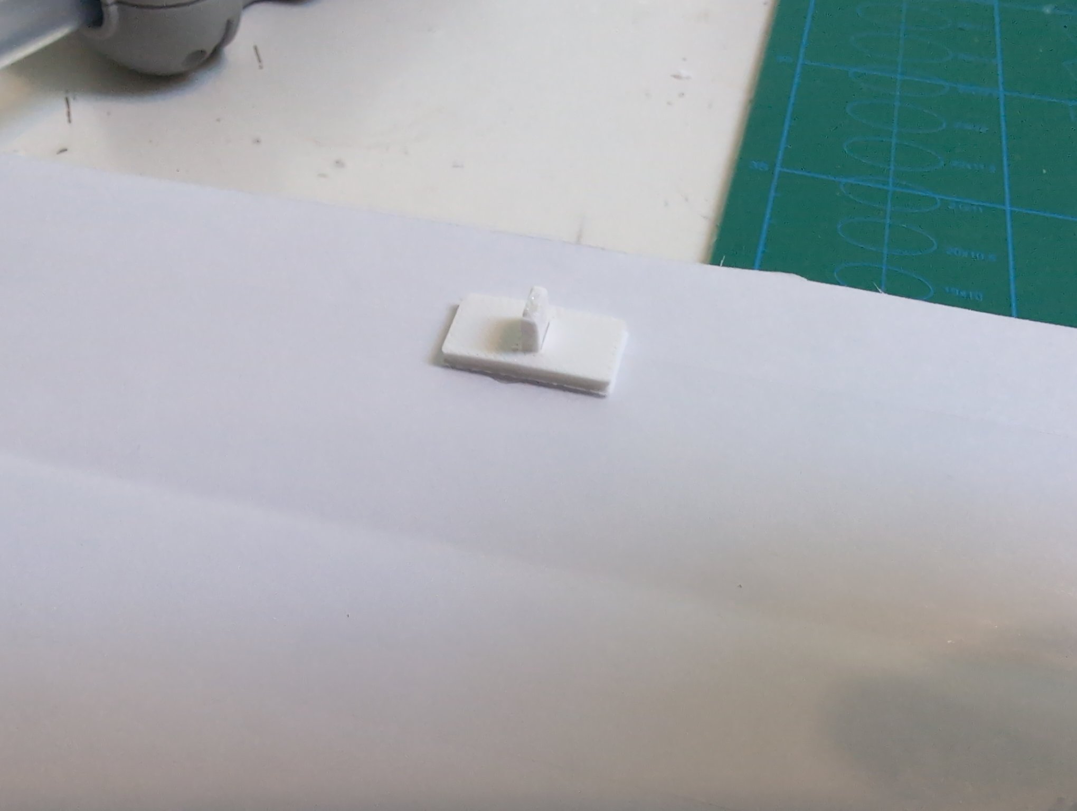
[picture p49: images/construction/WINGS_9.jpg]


You can connect your servo horn and control horn with a piece of bent 1.2mm wire. Here is some I bent myself.  
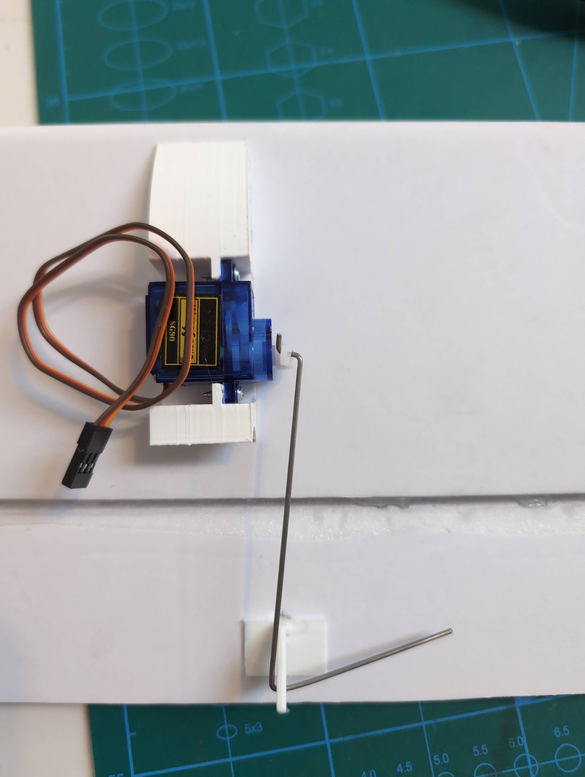
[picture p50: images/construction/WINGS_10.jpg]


You can also use the special screw-tightened nylon clips from the bill of materials.  
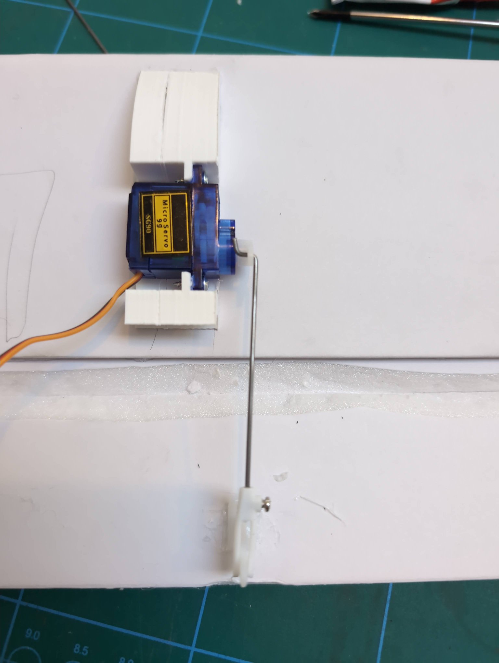
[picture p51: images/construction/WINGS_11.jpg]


Cut a hole near the servo for us to run the servo cable through. This hole is a bit large, feel free to make it smaller.  
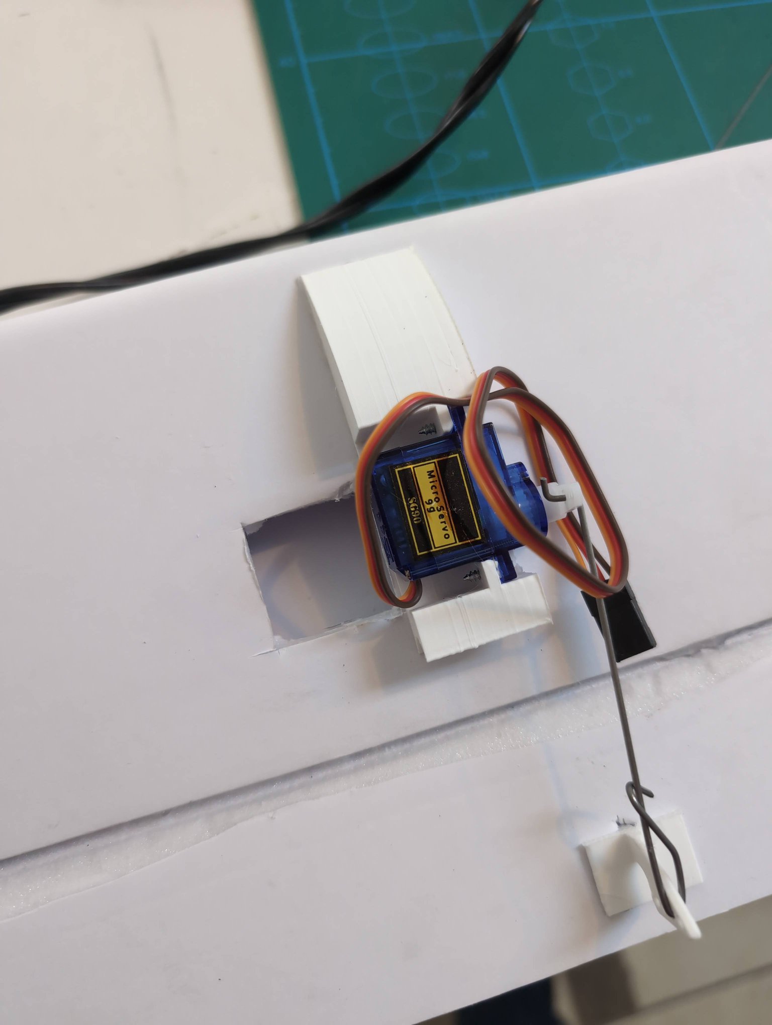
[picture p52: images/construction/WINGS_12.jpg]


I bend a stiff 0.8mm wire into a hook shape for pulling the servo cable through.  
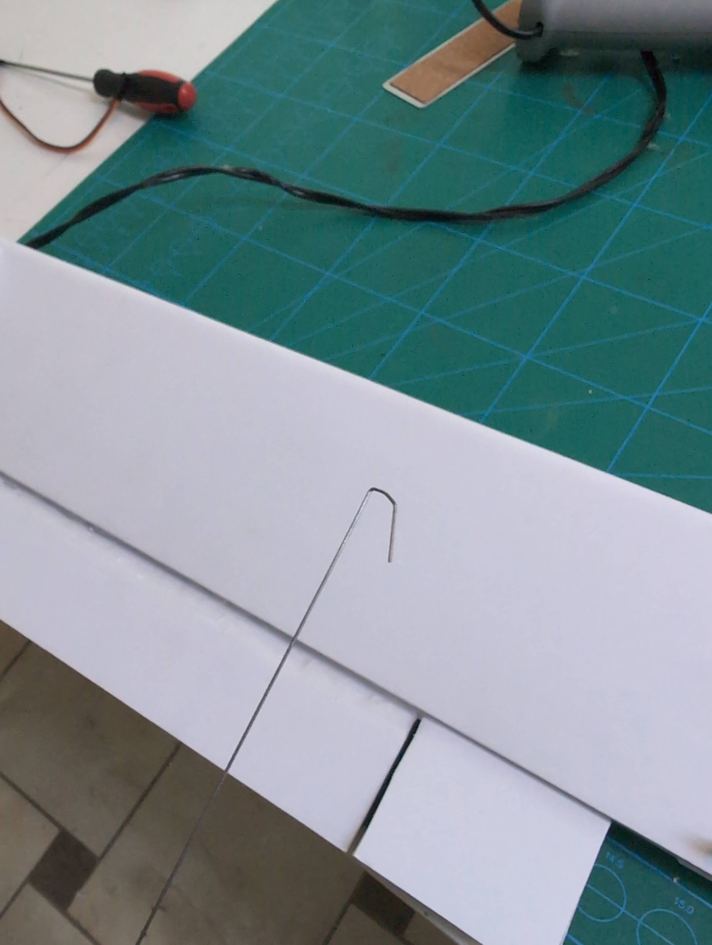
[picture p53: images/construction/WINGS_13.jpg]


Connect the servo cable to a 6" servo cable extender. Then it should be long enough to be pulled all the way through.  
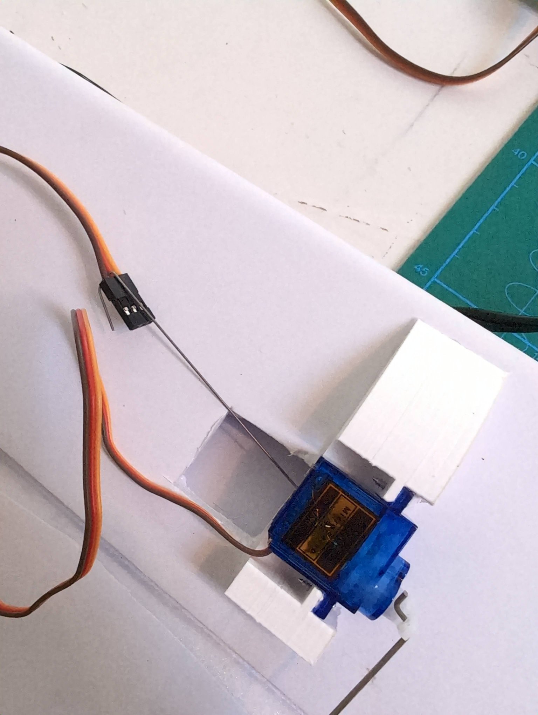
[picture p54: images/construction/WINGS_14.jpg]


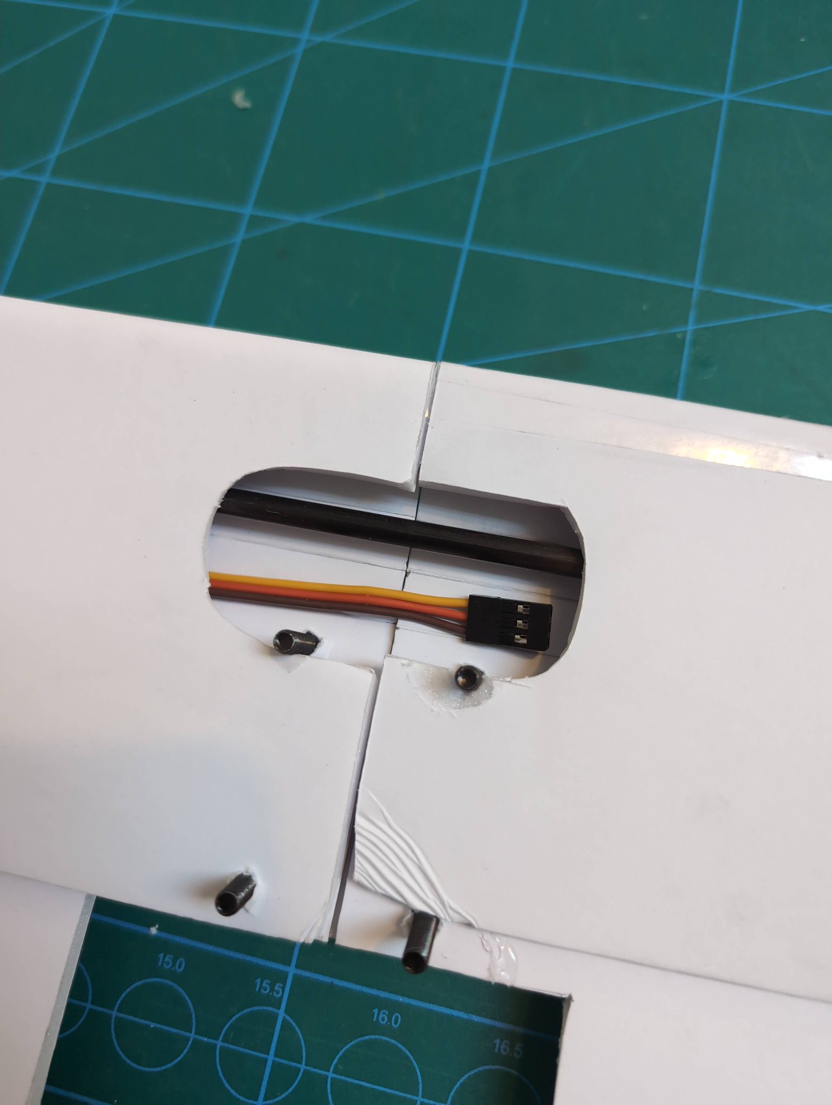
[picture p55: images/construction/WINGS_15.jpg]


Use packing tape to cover the hole.  
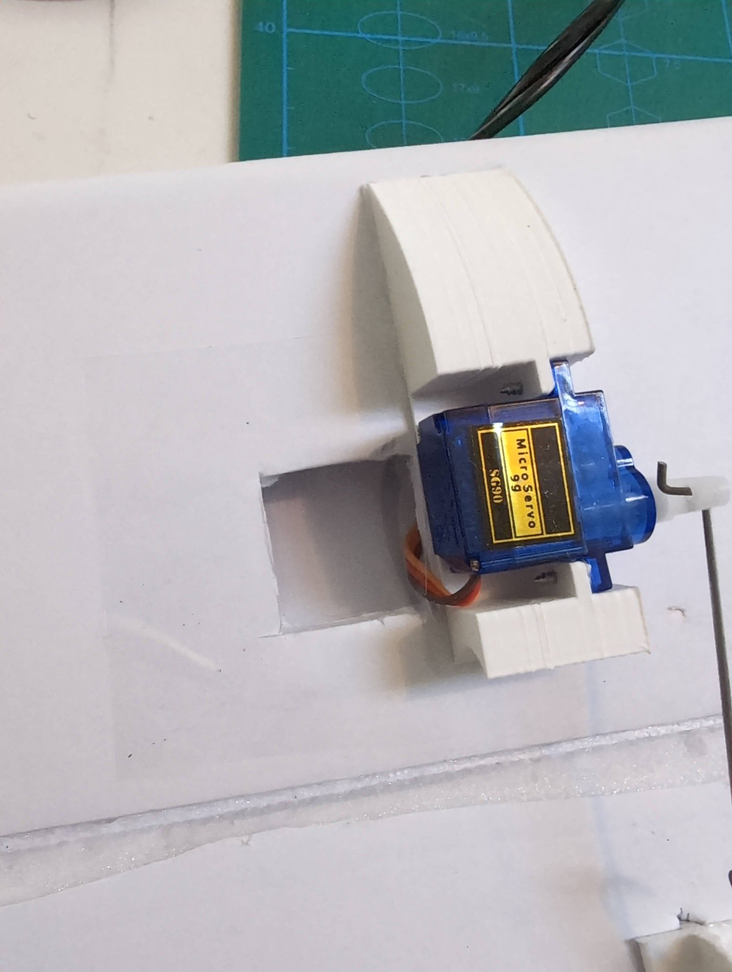
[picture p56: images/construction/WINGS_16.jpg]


#### CORRECTION ON WING SERVOS

Both aileron servos are controlled via the same PWM channel. But we want them to actuate in the opposite direction of one another. We will need to make sure each servo on each wing is facing the opposite direction. The absolute direction doesn't matter, because we can always invert the servo controls in the mix during the electronics configuration step.  

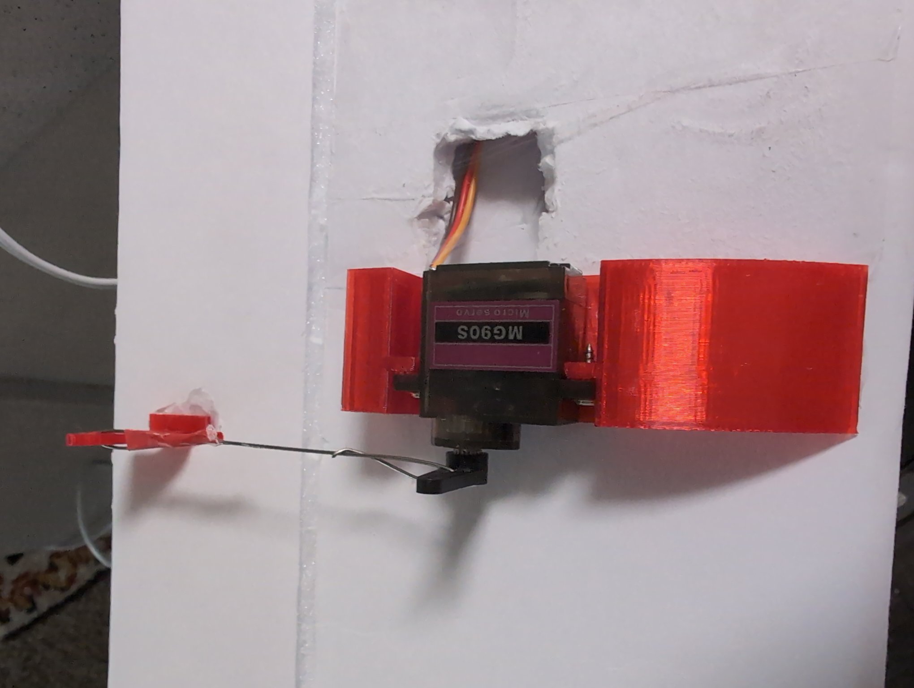
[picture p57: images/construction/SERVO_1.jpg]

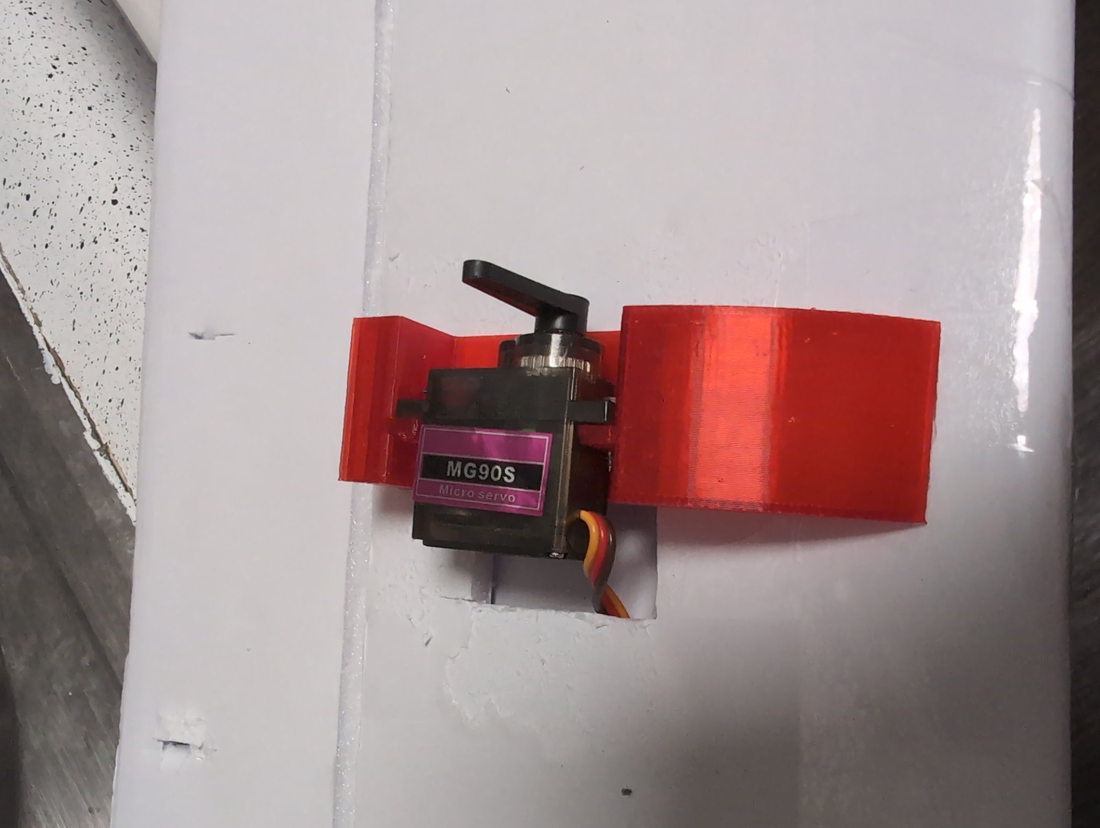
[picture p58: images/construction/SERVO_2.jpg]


Ignore that one of the servos did not fit the fairing properly. I made this discovery late in the design process, and didn't have time to print a mirrored servo fairing. Future versions of the build guide will have this corrected.  

### Final Assembly

#### Connecting the Tailfin Assembly and Pod Assembly

Next we are going to connect the tailfin assembly to the pod assembly. We are going to be limited by the length of our pushrods, so we will use them to get an idea for how long the tail needs to be.  
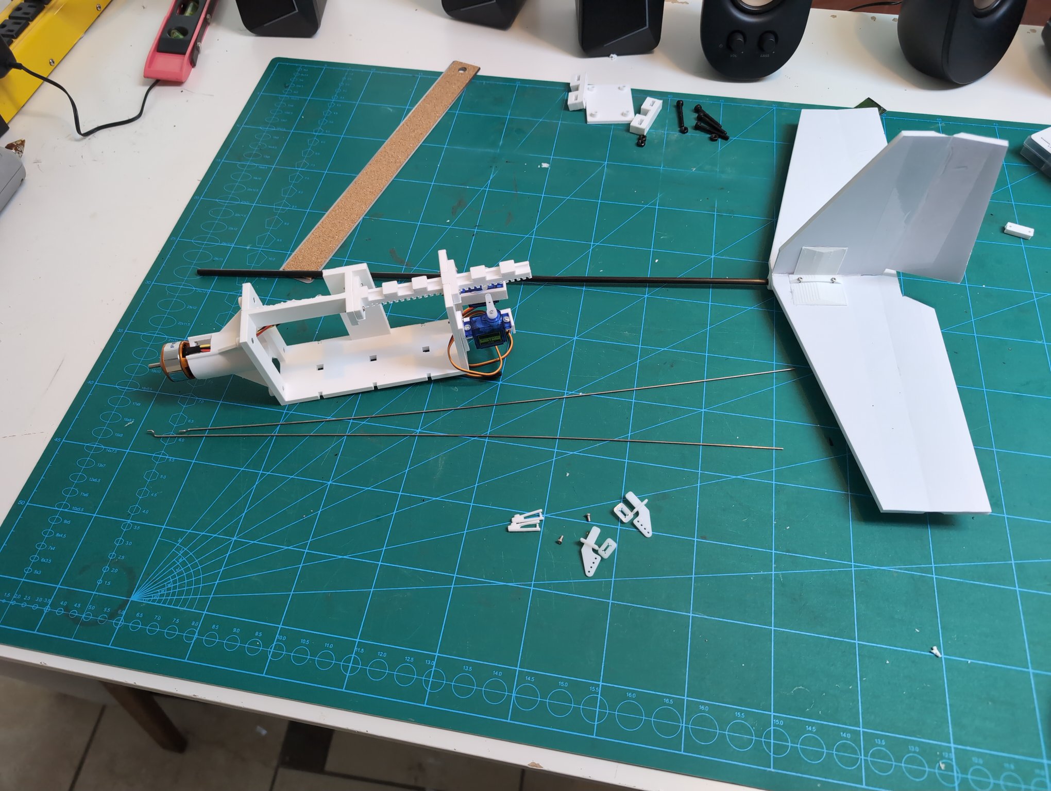
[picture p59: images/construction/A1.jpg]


Cut holes for the control horns.  
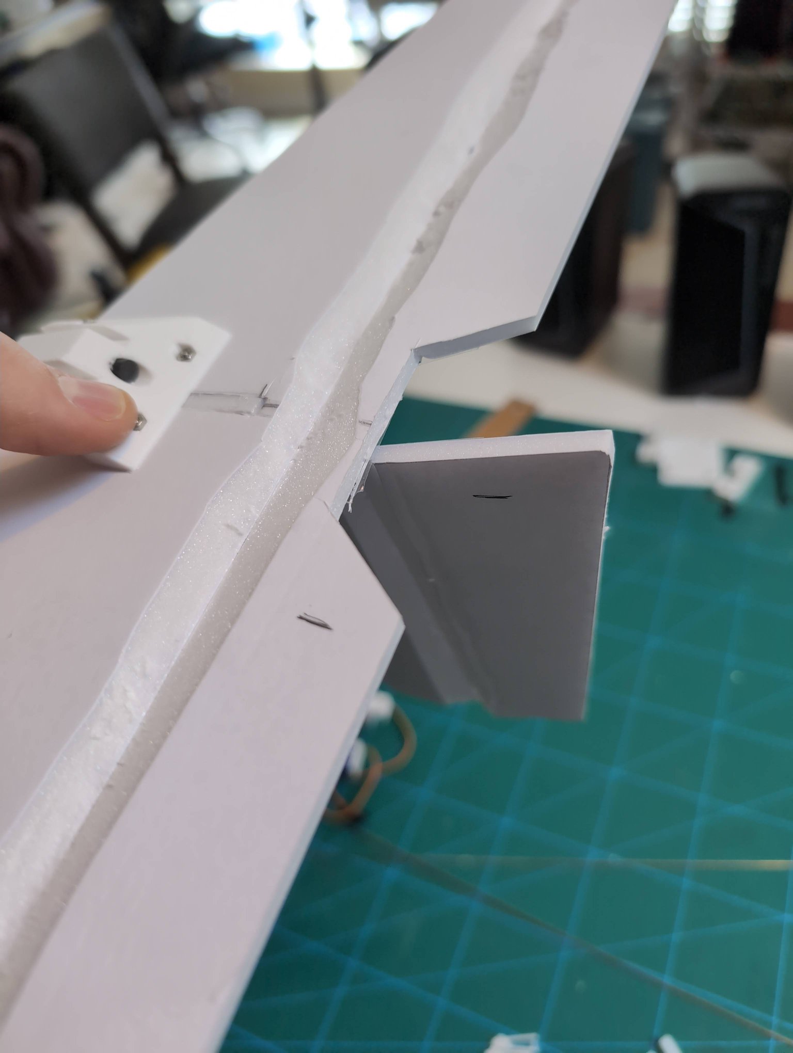
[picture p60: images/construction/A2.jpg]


In order to reduce bending, you can use a pushrod guide on the carbon fiber boom. Make sure it is in a position where the control rods are not pushing too hard against the walls of the guide. Secure it in place with glue.  


Connecting the tailfin assembly to the pod is the most challenging part of the build because you are at the mercy of the pushrods, and you cannot make changes in an arbitrary order (for example, you cannot hook the pushrod into the servos after connecting the pushrods to the control surfaces)

I find that the easiest order to do things in is:
1. Hook pushrods into servo horns
2. Slide carbon fiber boom into wing rail
3. Slide wire guide onto boom, and insert pushrods
4. Attach tailfin assembly onto carbon fiber boom
5. Tweak tailfin assembly position, and pushrod connector positions until the control surfaces are trim when the pushrod is taut without slack.

Example of tailfin assembly control surfaces with connectors and pushrods.  


Use a piece of tape to mark the location of the tailfin assembly. Remove the carbon fiber boom from the pod. Insert the carbon fiber boom into the tailfin assembly, and use glue to secure it permanently in place.  


Next we will use the carbon fiber boom clamp to clamp the boom in place on the pod. I add a dab of hot glue into the clamp to increase friction, since the hot glue is more malleable than the PETG and will "squish" onto it more. 

> Sidenote, due to the nature of the clamping force, I expect that this piece might experience significant creep over long periods of time. You should check that the tailfin is solidly secured before flying after a long period of inactivity.  



Make sure the tailfin is aligned before finalizing the position with the boom clamp.  


The boom clamp can be placed anywhere on the rail, but this position is the best (you will see why later). Use two 16mm length M2 screws to tighten the clamp.  


Once the tailfin position is finalized, you can make fine adjustments to the control surfaces by tweaking the amount of "choke" on the control horn clips.  



#### Balancing the Wings

TODO: ADD LINK TO WING BALANCING IN EDUCATIONAL REPO

Wing balancing is incredibly important if we want to have good flight characteristics. Due to the modular nature of this drone, I designed a wing mounting rail that allows the wing position to be adjusted so that the Center of Lift can be repositioned for different payloads.

The Wing Rail Screw Receivers have two slots for M4 nuts. Before use, I use 30mm length M4 screws to hold the nuts in position, then apply superglue or hot glue to the nut so that it will not fall out of the slot when the screw is removed. Be careful not to get glue on the M4 screws, or you will be unable to remove them without dislodging the nut as well.  


Here are the Wing Rail Screw Receivers after the glue has dried.   


Wing balancing is pointless unless the drone is loaded with our expected payload. For this build I am using a 3S 2200MAh battery, a 30A ESC, and a BetaFPV Micro ELRS receiver. I attach the scratchy side of the velcro to the pod, since the fuzzy side wears out more quickly. Also the scratchy side picks up hair and grass and it is easier to keep clean if it stays inside the drone.  


Here the pod is packed with electronics.  


Using two objects of the same height with a small point of contact, balance your plane so that it is level.  


We adjust our wing's position on the rail until we find a good balance point.  


Here we can see that the plane is balanced when the point of contact is about 25-30% of the wing's width away from the leading edge. A good rule of thumb is for your center of gravity to be at 1/4th of the Mean Aerodynamic Chord, which for our purposes is just the width of the wing. Once a good balance point is found, mark the location of your Wing Rail Screw Receivers on the rail with a sharpie or pen.  


Using the marks made earlier, glue the Wing Rail Screw Receivers onto the rail. This will be a fairly weak joint that is broken easily by pushing down too hard, so when attaching the wing do so carefully. The wing can be mounted on an un-glued Wing Rail Screw Receiver, but it is a pain.  


#### Adding Fairings

When attaching the front fairing to the motor mount, apply a small amount of hot glue around the base of the cylinder. Then you can just slide the mount on.  


TODO: design the rear fairing (it is harder than you think!!!)

### FINISHED

Congratulations!

  


### Tips and Tricks

#### Servos

There is a difference between the MG90S and SG90 servo. The MG90S has metal gears, and the SG90 has plastic gears. 
The MG90S weighs about 13g and the SG90 weighs 9g. Using SG90 servos saves 16g overall, which is pretty significant. But MG90S servos are less likely to shear under heavy load. I think SG90 servos are fine for this application. Make sure you get SG90 if you are concerned about weight reduction.

#### Armin Wing Construction

Armin Wings are hard to make (relative to everything elsein this build guide). I recommend watching multiple videos to see how others make them.

[Armin Wing Part 1](https://www.youtube.com/watch?v=UNqFnzmm0vI)  
[Armin Wing Part 2](https://www.youtube.com/watch?v=RgBSbnZh_KM)  
[Armin Wing Part 3](https://www.youtube.com/watch?v=-z_mBiPw6z0)  
[Armin Wing Part 4](https://www.youtube.com/watch?v=idnT5eP5Snw)  

Alternative guide:
[Armin Wing Full Build Guide](https://www.youtube.com/watch?v=karr67ZYho4)  

#### Other

**Overture AIR PLA**
Print with normal Generic PLA settings, but disable dynamic flow calibration, and reduce volumetric flow rate by 75% (if it was 12mm^3/s before, change it to 3mm^3/s). Use an untextured plate and apply gluestick beforehand. AIR PLA has a horrible time with adhesion on the first layer. Make sure the filament is dehydrated, as AIR PLA seems to be more susceptible to moisture than normal PLA.

**Print the Electronics Payload at an angle on the Bambu A1 Mini**
There may be temperature issues at the edges of the printing plate on the Bambu A1 mini. Try printing it at an angle to see if that helps at all.

**Do your wing balancing before you cut your push rods for the tailfin control surfaces to length**   
It is easier to adjust your balance by moving the tailfin position, so the length of your tailfin will be dependent on the balance. Once that is determined, then you can adjust the length of your pushrods. I would recommend doing balancing several times throughout the build process.

**Use 1.2mm wire control rods for tail control surfaces**  
The tail control surfaces are far away from the servos, and 0.64mm piano wire will deform. 1.2mm wire is thick enough to withstand the forces, while also deflecting the desired amount along its path from the servo to the control surface.

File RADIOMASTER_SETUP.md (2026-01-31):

# Electronics Setup

---
  Radiomaster Pocket Button Layout

  [PAGE <]  [PAGE >]      ← Top shoulder buttons

           [SPEAKER]
  [SYS]               [MDL]    ← Side buttons

      [SCROLL WHEEL]           ← Press to select, rotate to navigate

  [RTN]                        ← Bottom left, goes back/exits

  ---
  Step 1: Create a New Model

  1. Press MDL button (right side of speaker)
  2. You'll see a list of model slots (some empty, some with names)
  3. Rotate scroll wheel to highlight an empty slot
  4. Press scroll wheel to open submenu
  5. Select Create Model → press scroll wheel to confirm
  6. A new model is created and you're now in its settings

  ---
  Step 2: Name Your Model

  1. After creating, press PAGE > once to reach the Setup menu
  2. First option is Model Name - it will show a default name like "Model01"
  3. Press scroll wheel to enter edit mode
  4. You're now in the character editor:
    - Rotate scroll wheel to change the current character (cycles through A-Z, a-z, 0-9, symbols)
    - Press scroll wheel to confirm that character and move to the next position
    - Repeat for each character
  5. When done, press RTN to save the name and exit editor

  ---
  Step 3: Configure Internal RF Module

  Still in the Setup menu:

  1. Rotate scroll wheel down to find Internal RF
  2. Press scroll wheel to edit
  3. Set Mode to CRSF (this enables ELRS)
  4. Press RTN to exit
  5. Scroll down to verify Receiver shows a number (receiver ID)

  ---
  Step 4: Set Up Channels (Method A: Wizard - Easiest)

  1. Press RTN to go back to home screen
  2. Press SYS button (left side of speaker)
  3. You're in the Tools menu
  4. Rotate scroll wheel to find Wizard Loader
  5. Press scroll wheel to open it
  6. Select Multi (for quadcopter/drone)
  7. Follow the prompts:
  ┌──────────────────┬────────────────────────────────────────────────────────────────────┐
  │      Prompt      │                             What to do                             │
  ├──────────────────┼────────────────────────────────────────────────────────────────────┤
  │ Throttle Channel │ Leave as CH3, press scroll wheel                                   │
  ├──────────────────┼────────────────────────────────────────────────────────────────────┤
  │ Roll Channel     │ Leave as CH1, press scroll wheel                                   │
  ├──────────────────┼────────────────────────────────────────────────────────────────────┤
  │ Pitch Channel    │ Leave as CH2, press scroll wheel                                   │
  ├──────────────────┼────────────────────────────────────────────────────────────────────┤
  │ Yaw Channel      │ Leave as CH4, press scroll wheel                                   │
  ├──────────────────┼────────────────────────────────────────────────────────────────────┤
  │ Arm Switch       │ Select SA (2-position switch on left shoulder), press scroll wheel │
  ├──────────────────┼────────────────────────────────────────────────────────────────────┤
  │ Mode Switch      │ Select SB (3-position switch), press scroll wheel                  │
  ├──────────────────┼────────────────────────────────────────────────────────────────────┤
  │ Beeper Switch    │ Select SC or SD, press scroll wheel                                │
  └──────────────────┴────────────────────────────────────────────────────────────────────┘
  8. On confirmation screen, long-press scroll wheel to finish

  ---
  Step 4: Set Up Channels (Method B: Manual)

  Navigate to Mixes

  1. From home screen with your model selected, press MDL
  2. Press PAGE > three times to reach Mixes

  Add Arm Switch to CH5

  1. Scroll down to CH5 (it will be empty)
  2. Press scroll wheel → select Edit (or just press to add)
  3. You'll see a source selection screen
  4. Flip the switch you want to use (e.g., SA) - the radio auto-detects it
  5. The source will show SA (or whichever switch you flipped)
  6. Press RTN to save

  Add Flight Mode Switch to CH6

  1. Scroll to CH6
  2. Press scroll wheel
  3. Flip switch SB (3-position switch)
  4. Press RTN

  Add Beeper to CH7

  1. Scroll to CH7
  2. Press scroll wheel
  3. Flip switch SC or SD
  4. Press RTN

  ---
  Step 5: Verify Your Setup

  1. Press RTN until you're at the home screen
  2. Press MDL → PAGE > three times to Mixes
  3. Move sticks and flip switches - you should see the channel values change on screen:
  ┌─────────┬────────┬──────────────────────────────────────────┐
  │ Channel │ Source │              Expected Value              │
  ├─────────┼────────┼──────────────────────────────────────────┤
  │ CH1     │ Ail    │ -100 to +100 with right stick left/right │
  ├─────────┼────────┼──────────────────────────────────────────┤
  │ CH2     │ Ele    │ -100 to +100 with right stick up/down    │
  ├─────────┼────────┼──────────────────────────────────────────┤
  │ CH3     │ Thr    │ -100 to +100 with left stick up/down     │
  ├─────────┼────────┼──────────────────────────────────────────┤
  │ CH4     │ Rud    │ -100 to +100 with left stick left/right  │
  ├─────────┼────────┼──────────────────────────────────────────┤
  │ CH5     │ SA     │ Jumps between -100/+100 when flipped     │
  ├─────────┼────────┼──────────────────────────────────────────┤
  │ CH6     │ SB     │ Shows -100/0/+100 for 3 positions        │
  └─────────┴────────┴──────────────────────────────────────────┘
  ---
  Quick Reference: Switch Names on Radiomaster Pocket
  ┌────────┬───────────────────────┬────────────┬──────────────┐
  │ Switch │       Location        │ Positions  │   Good For   │
  ├────────┼───────────────────────┼────────────┼──────────────┤
  │ SA     │ Left shoulder, front  │ 2-position │ Arm          │
  ├────────┼───────────────────────┼────────────┼──────────────┤
  │ SB     │ Left shoulder, back   │ 3-position │ Flight modes │
  ├────────┼───────────────────────┼────────────┼──────────────┤
  │ SC     │ Right shoulder, front │ 2-position │ Beeper       │
  ├────────┼───────────────────────┼────────────┼──────────────┤
  │ SD     │ Right shoulder, back  │ 2-position │ Turtle mode  │
  └────────┴───────────────────────┴────────────┴──────────────┘
  ---
  Sources:
  - https://www.flitetest.com/articles/creating-a-new-model-on-the-radiomaster-pocket
  - https://oscarliang.com/setup-radiomaster-pocket/

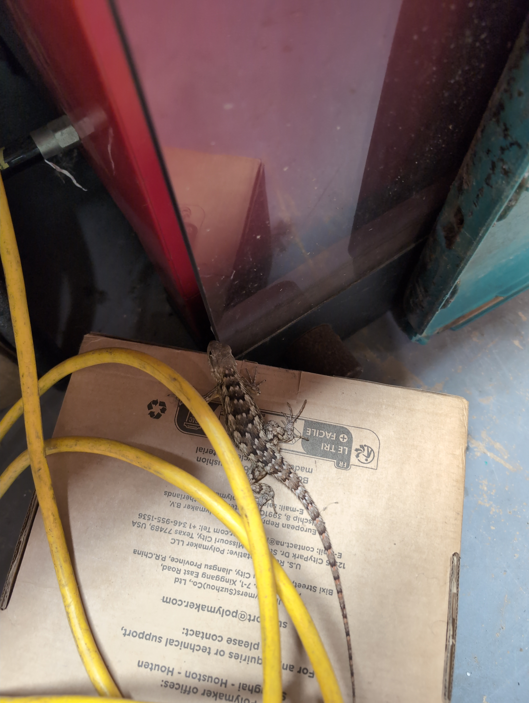
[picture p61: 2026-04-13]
images/construction_v2/IMG_20260413_110927_881.jpg

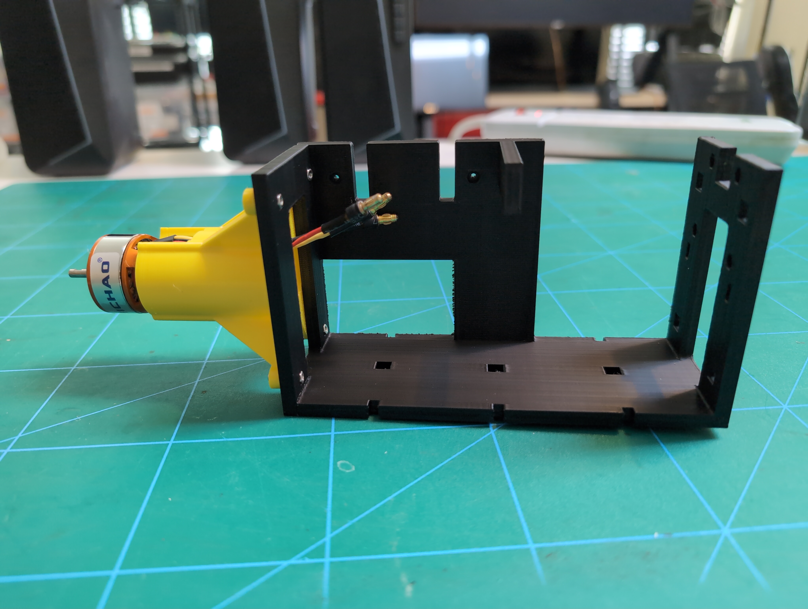
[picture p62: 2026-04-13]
images/construction_v2/IMG_20260413_114347_257.jpg

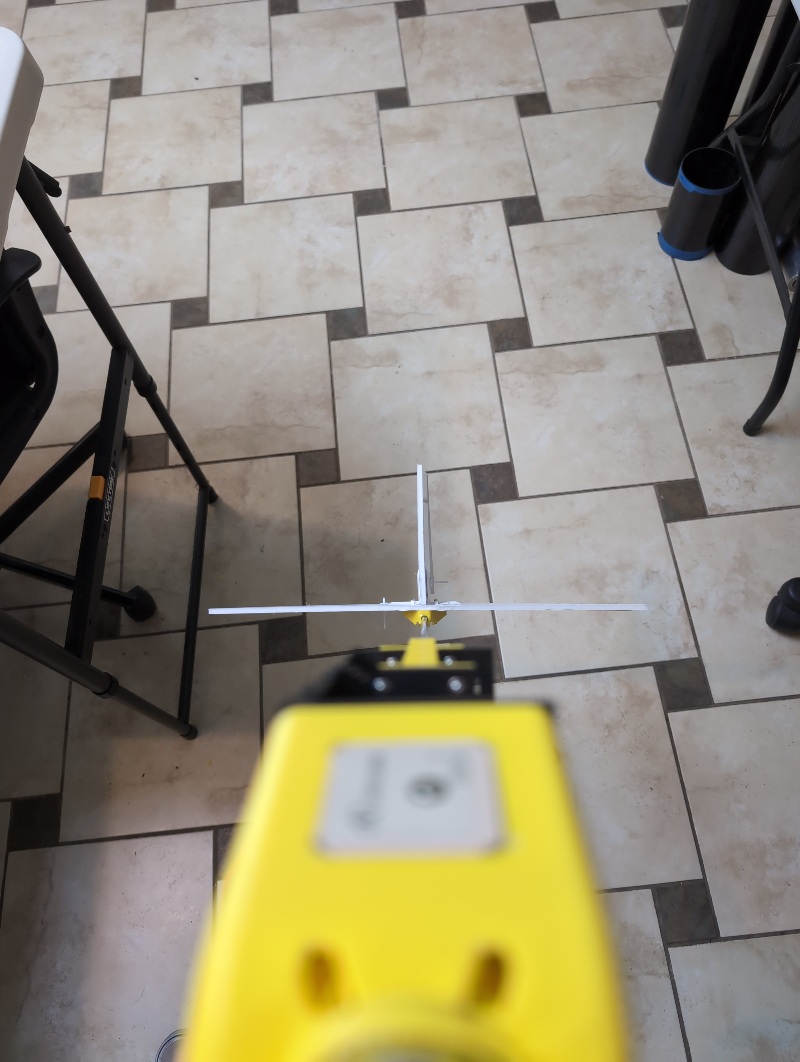
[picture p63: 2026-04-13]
images/construction_v2/IMG_20260413_121348_797.jpg

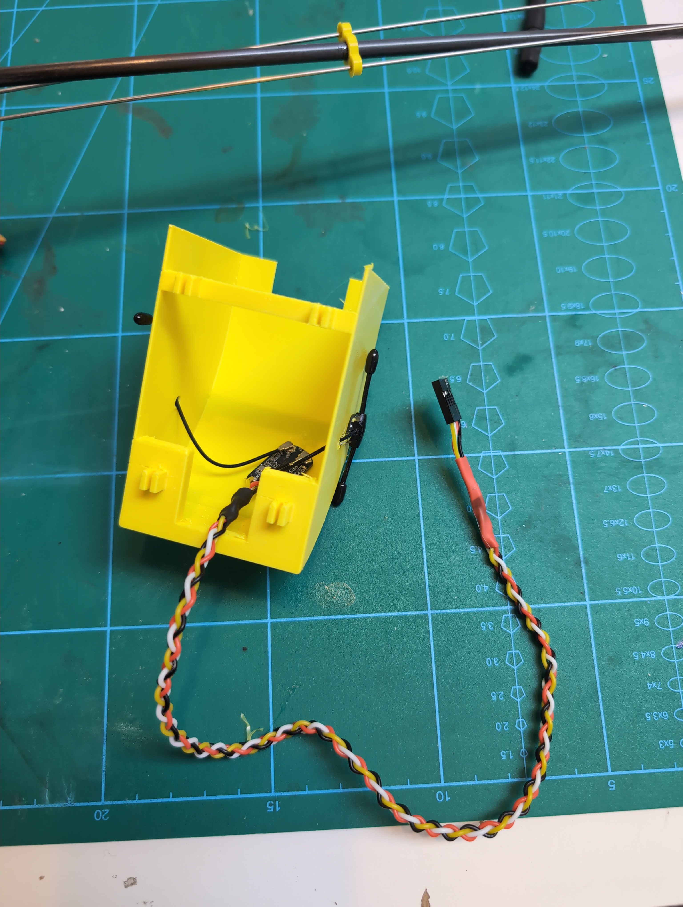
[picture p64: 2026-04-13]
images/construction_v2/IMG_20260413_122343_999.jpg

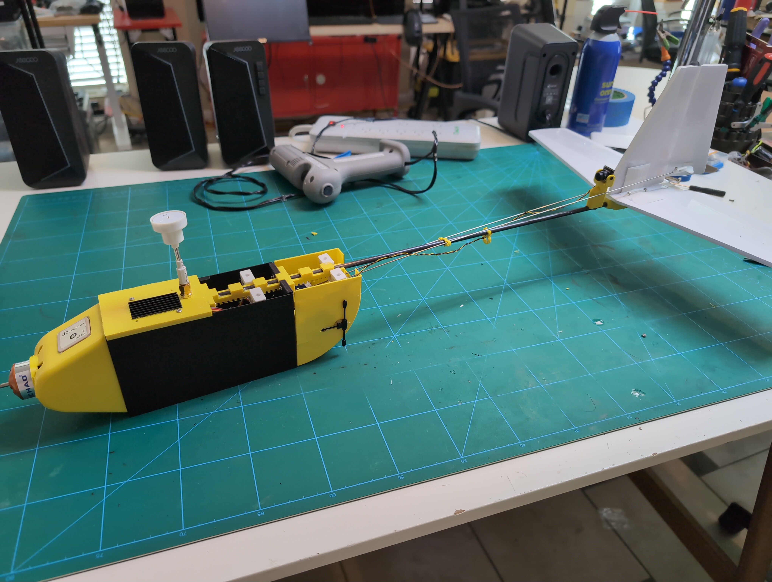
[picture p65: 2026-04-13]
images/construction_v2/IMG_20260413_130014_283.jpg

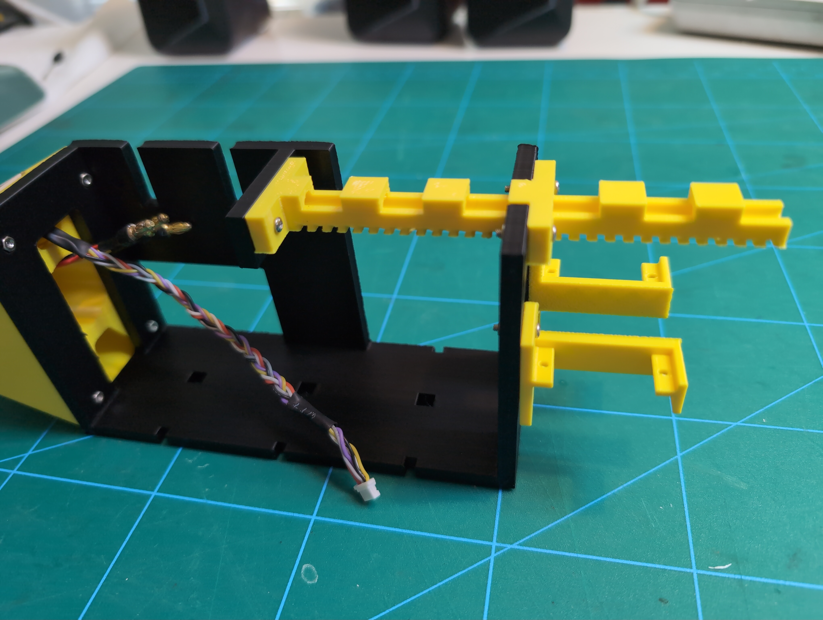
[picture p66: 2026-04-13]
images/construction_v2/IMG_20260413_115051_045.jpg

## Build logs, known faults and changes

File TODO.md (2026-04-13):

# TODO

- [ ] create winglets
- [ ] get motor working
- [ ] Static plane test 

### Documentation
- [ ] document assembly
    - [ ] update CAD BOM
- [ ] document electronics setup
    - [ ] electronics BOM
    - [ ] all parts
    - [ ] soldering
    - [ ] wiring
        - [ ] braided wires
    - [ ] flashing
    - [ ] setup
        - [ ] inav
        - [ ] edgetx
- [ ] wiring diagrams

VTX CONNECT TO SPEEDYBEE:
tx5 is smartaudio, vv is voltage+ for the vtx, and VTX is video
so as it is labelled, Vv = 7-26v input, GND = GND, TX5 = smart audio, and VTX = video
        
- [x] build brand-new drone from scratch (again)
- [ ] update assembly guide with rear fairing, updated CF rod assembly info, opposing servo positions, and updated pushrod configuration (mor authority)
- [ ] update electronics guide
    - [x] no FC
    - [ ] with FC

## Maiden Flight Feedback

10mph winds with 25mph gusts

Cons: 

Extremely hard to handle in wind due to high aspect, low authority, and torsional displacement of tailfin.

- Too much torsional displacement in tail. Need to try Carbon Fiber tube instead of rod (this should also save on mass a bit)

- Low authority. Attach pushrods to the far end of the servo horn, but close end of the control surface horn.

- all controls had to be inverted. Left roll should raise left aileron, pitch up should raise elevator, yaw right should move rudder right. Document how to invert the mix in edge tx

Pros:
- 30mins estimated flight
- extremely good glide slop

## FC Flight

## 3D CAD

Wing screw-in hole spacing: 40mm long, 30mm wide

1/13/2026 -- 730g fully-loaded
1/27/2026 -- 775g fully-loaded, no rear fairing

### WEBSITE TODO
- [ ] add mockingbird videos to website
- [ ] add corvus flight footage to website
- [ ] update docs and information on website

### Engineering Docs
- [ ] interface control document
- [ ] power budget
- [ ] mass growth allowance
- [ ] TRL assessment
- [ ] iterate

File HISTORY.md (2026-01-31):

# History

Here is some history of the project to prove I didn't know anything about drones before starting.

Playing around with foam to figure out how big the pod needs to be:  
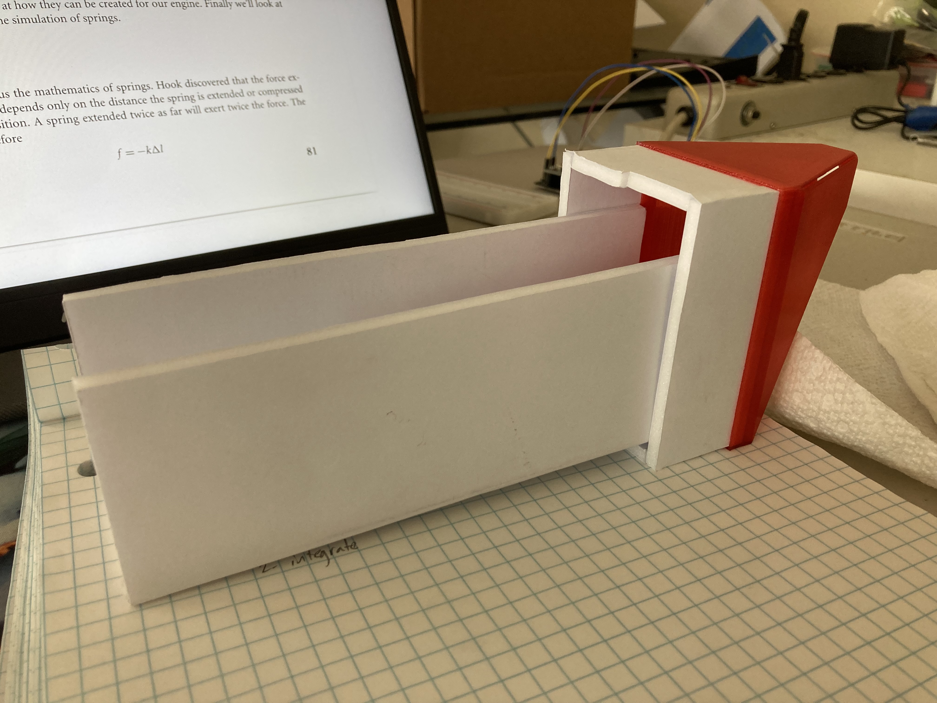
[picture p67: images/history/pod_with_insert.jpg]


First Wings:  
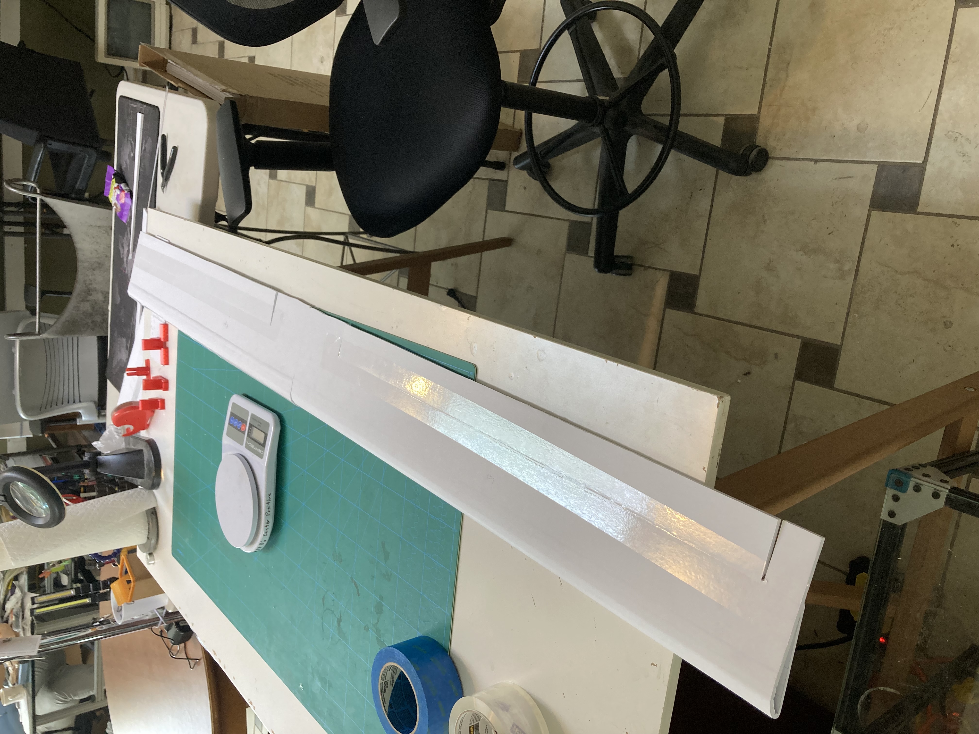
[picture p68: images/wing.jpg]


Pod and Wings:  
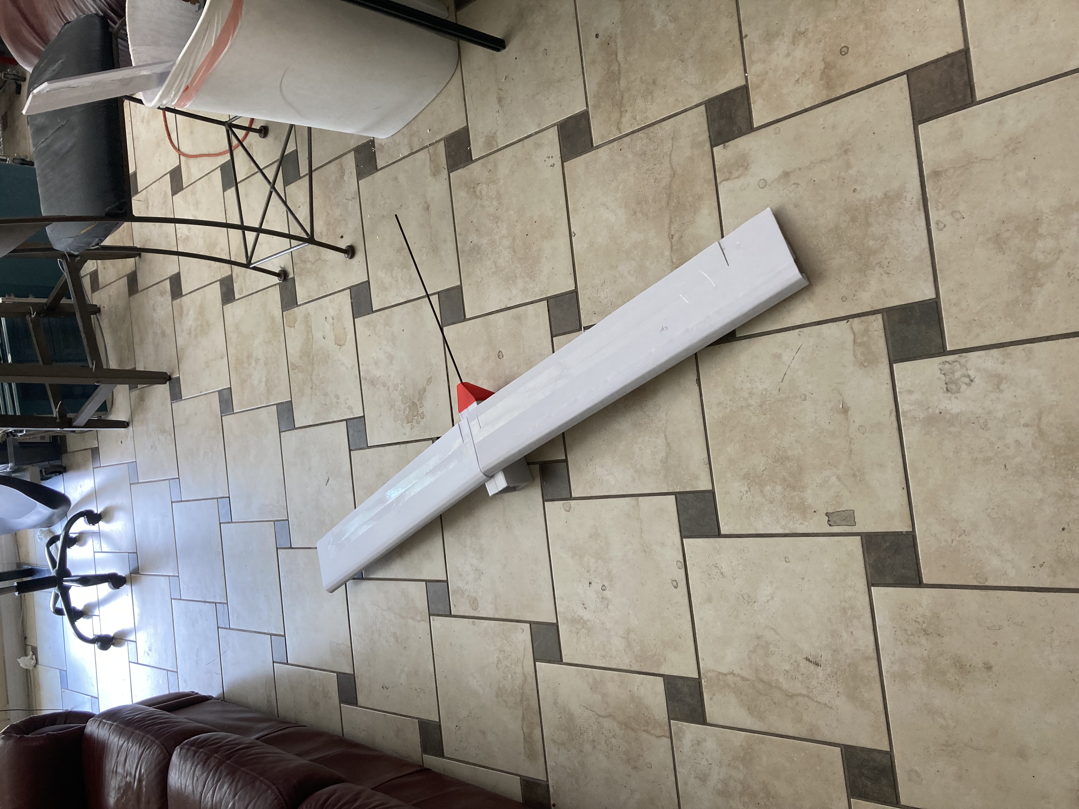
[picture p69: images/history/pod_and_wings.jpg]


Mockingbird "Payload" first print:  
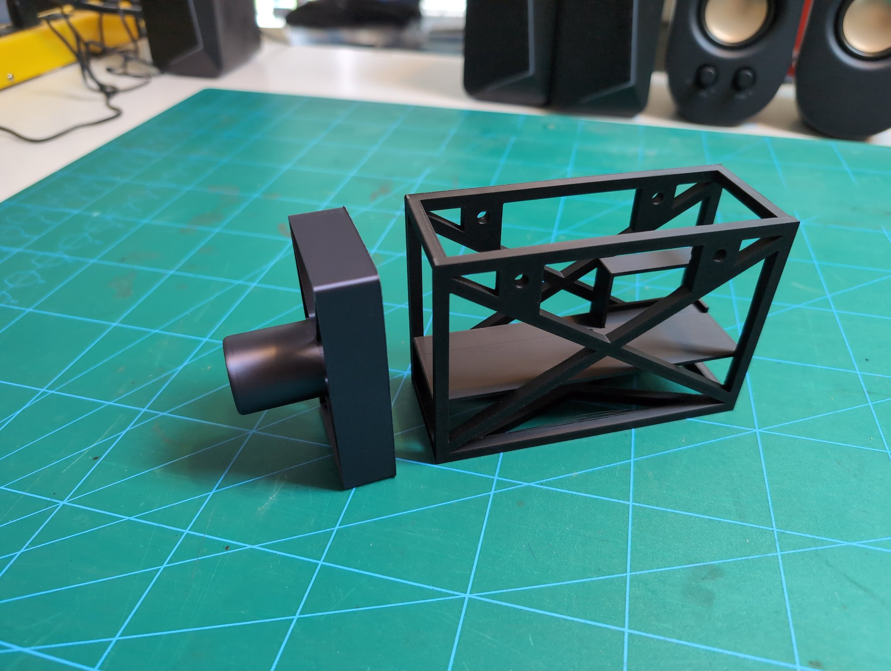
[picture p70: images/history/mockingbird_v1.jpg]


Mockingbird "Payload" second print:  
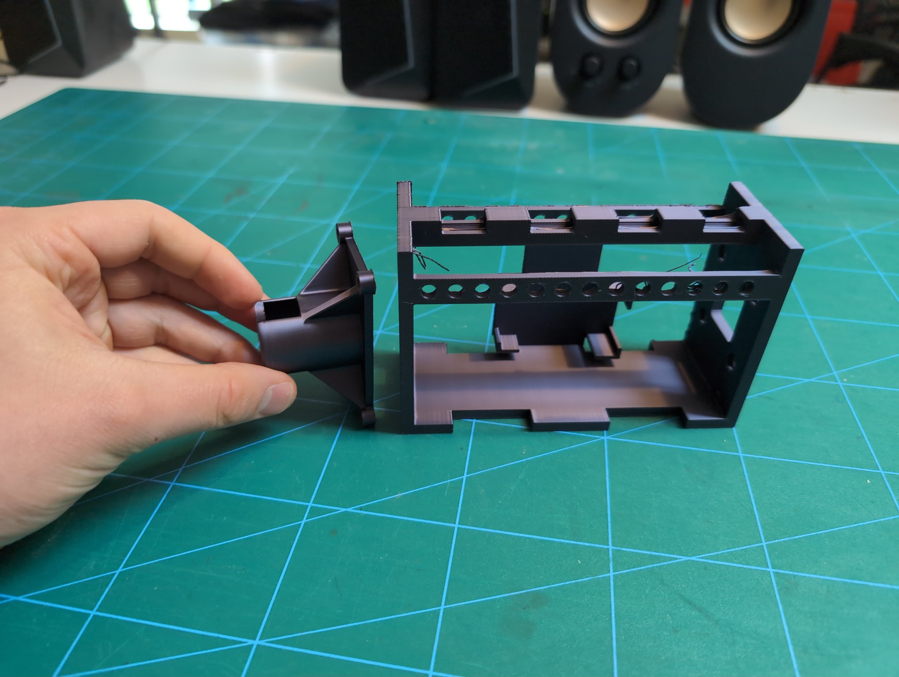
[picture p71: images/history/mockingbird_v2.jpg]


Mockingbird prototype wing balancing test:  
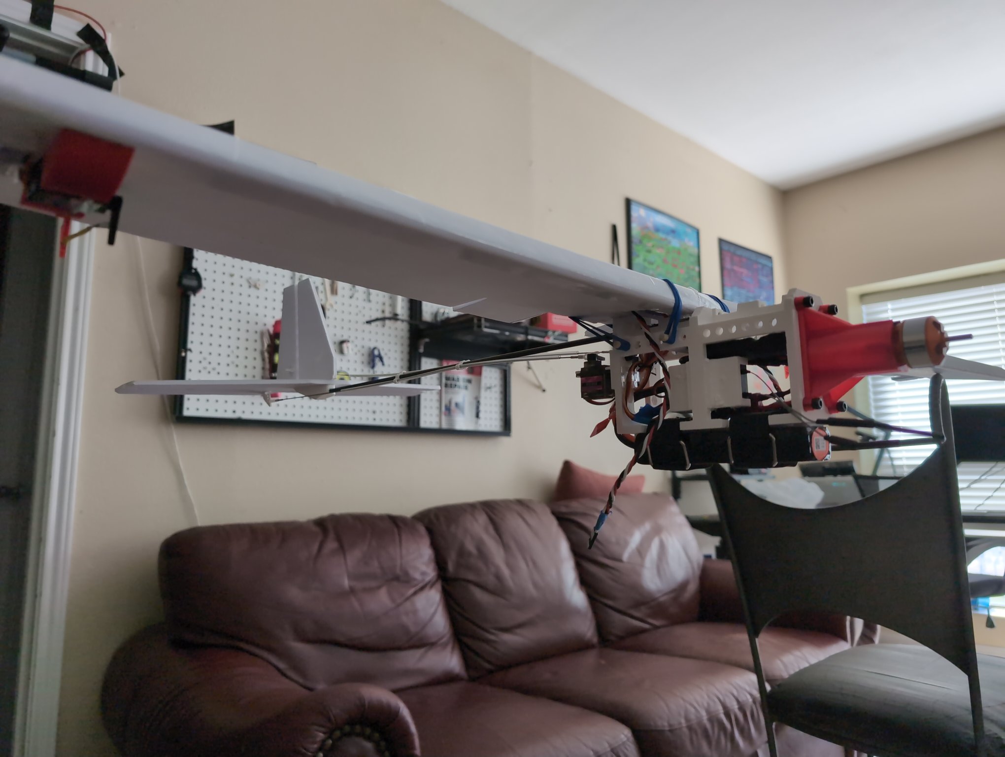
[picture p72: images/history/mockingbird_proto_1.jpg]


Prototype evolution:  


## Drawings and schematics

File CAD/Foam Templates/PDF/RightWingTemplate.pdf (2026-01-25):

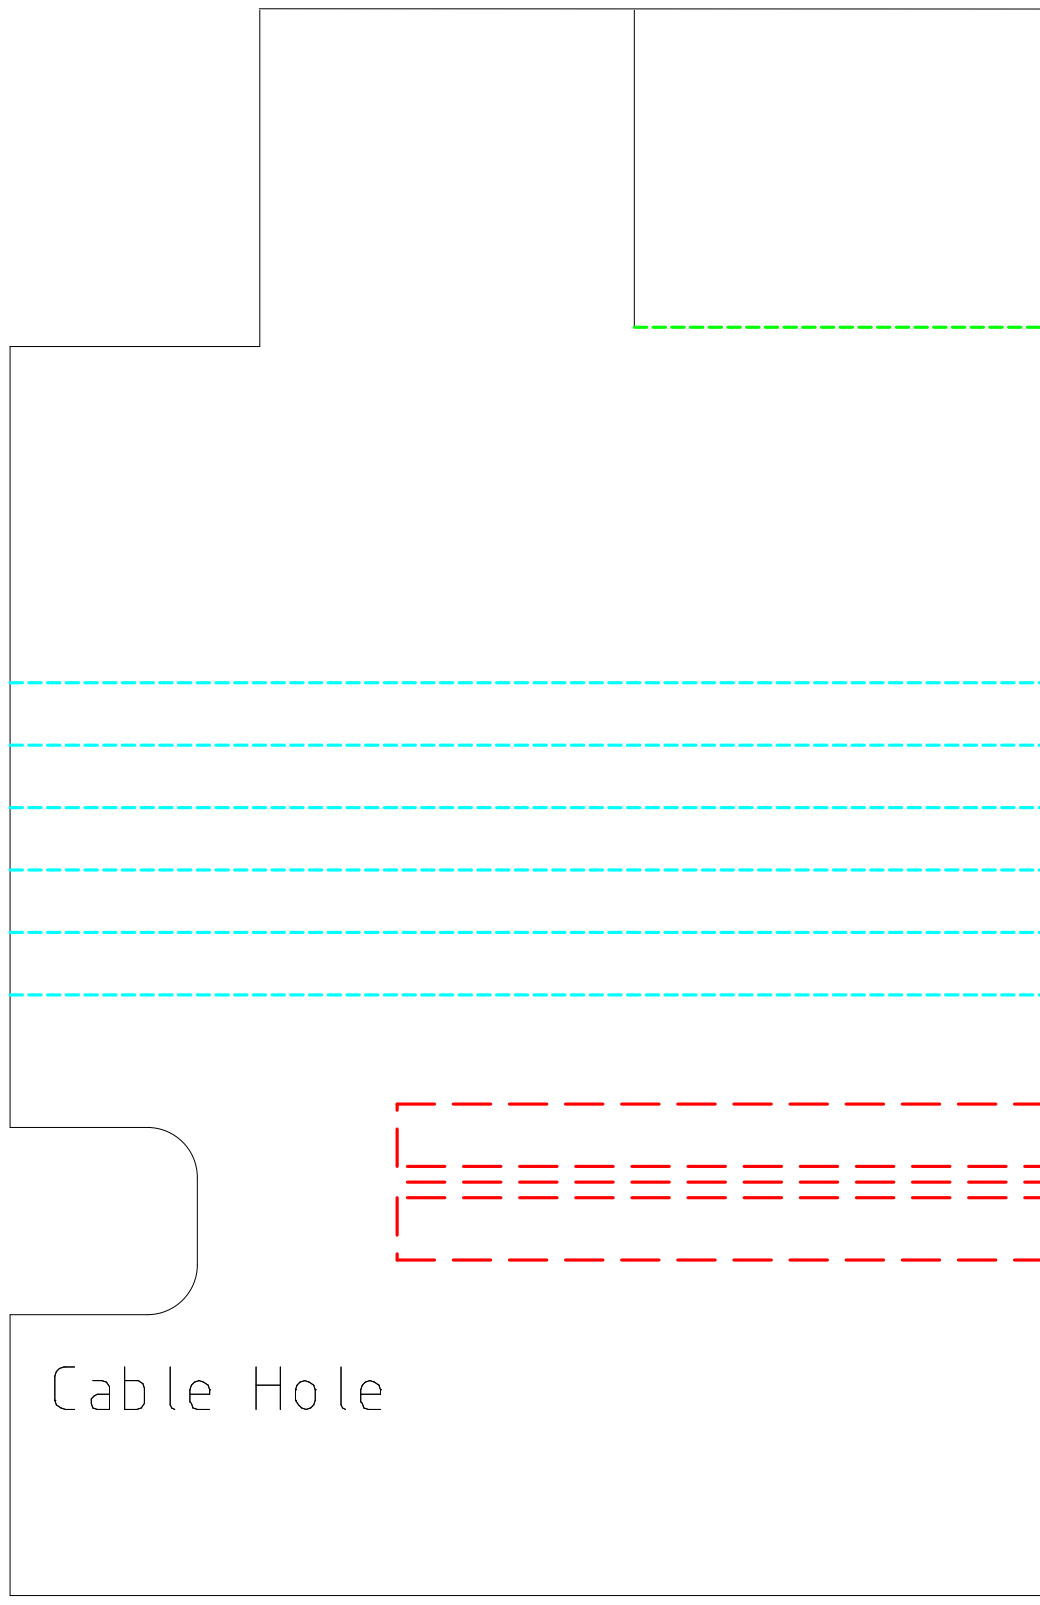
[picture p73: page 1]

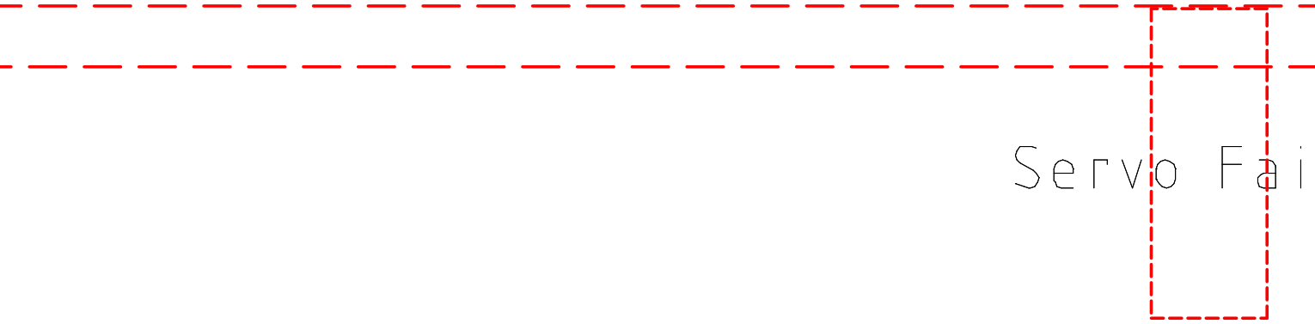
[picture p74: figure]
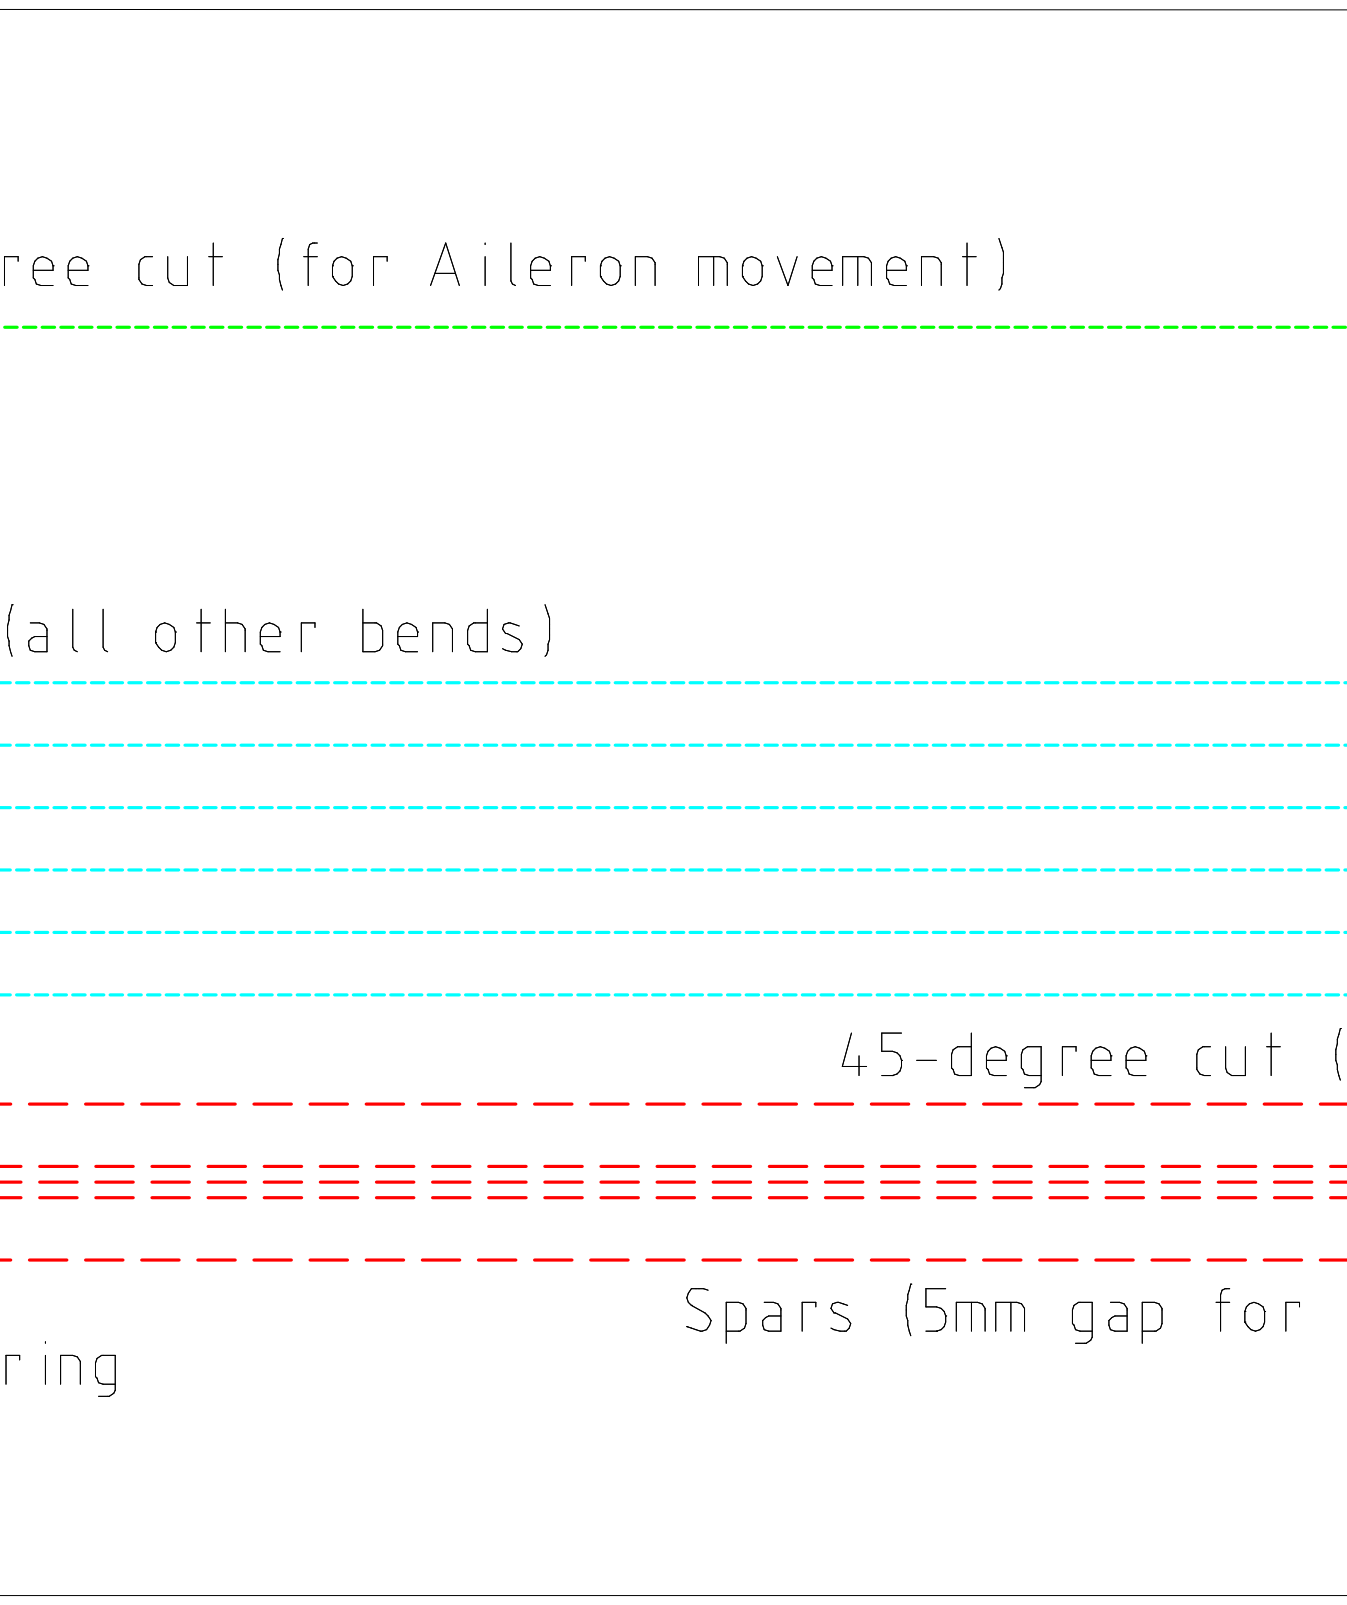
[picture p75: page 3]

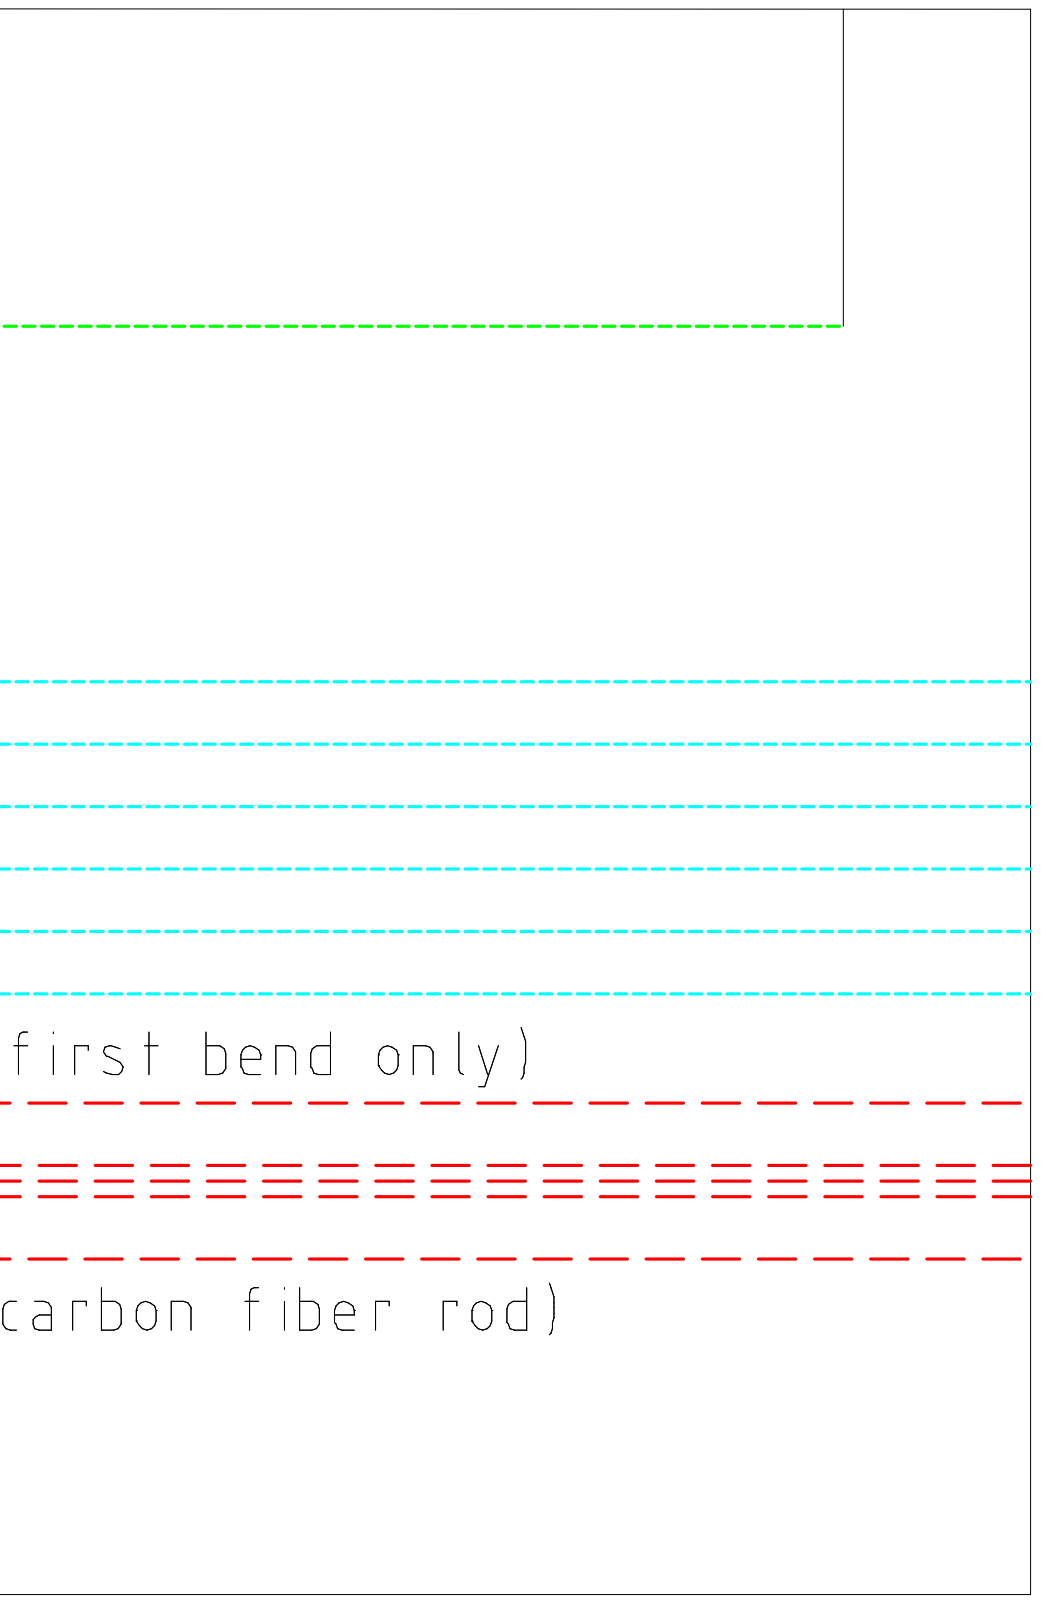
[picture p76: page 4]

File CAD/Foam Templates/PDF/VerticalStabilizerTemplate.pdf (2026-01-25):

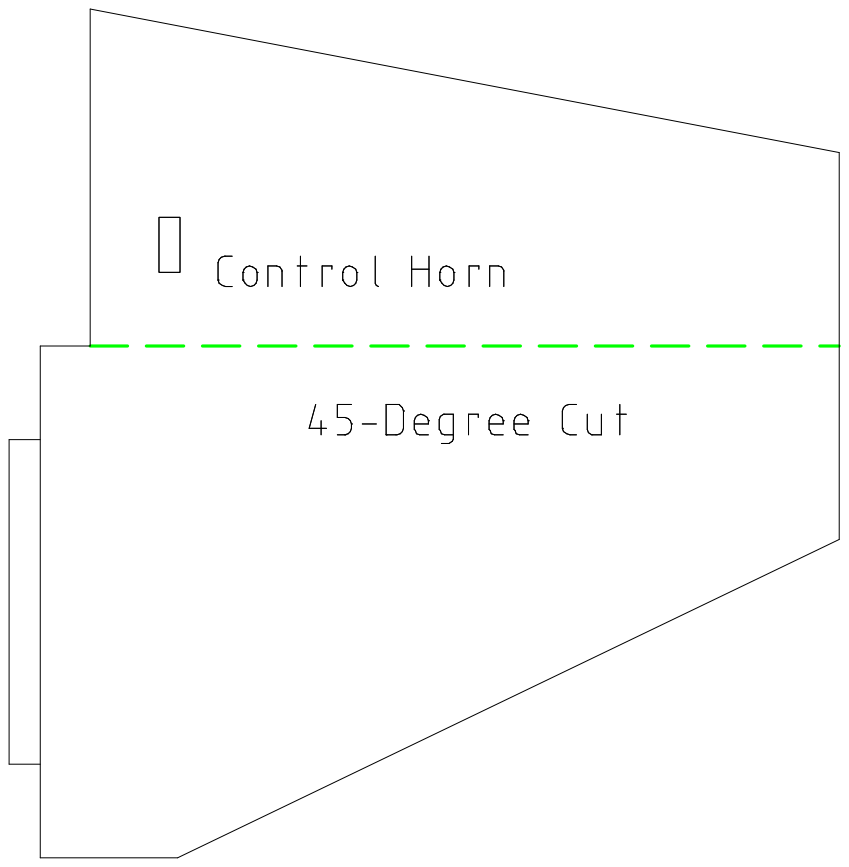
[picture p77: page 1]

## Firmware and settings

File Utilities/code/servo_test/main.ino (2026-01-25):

#include <ESP32Servo.h>
    
Servo myServo; // Create a servo object
const int servoPin = 18; // Define the GPIO pin for the servo

void setup() {
  myServo.attach(servoPin); // Attach the servo object to the pin
}

void loop() {
  myServo.write(0); // Move to 0 degrees
  delay(1000);
  myServo.write(90); // Move to 90 degrees
  delay(1000);
  myServo.write(180); // Move to 180 degrees
  delay(1000);
}

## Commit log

2026-01-25 Big refactor
    [ArminWing.FCStd, BOTTOM_FAIRING.3mf, BOTTOM_FAIRING.stl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]
2026-01-28 Added images for the build guide
    [5mmFoamBoardMiterCutter.stl, Foam_board_90_degree_cutter.stl]
2026-01-30 Updated some CAD files
    [PETG_COMPONENTS.3mf, SERVO_FAIRINGS.3mf, ServoFairing-Left.stl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]
2026-01-30 Assembly guide is finished (for now)
2026-01-31 Updating BOM and stuff
    [CarbonFiberBoomClampBottom.stl, CarbonFiberBoomClampTop.stl, CarbonFiberClampBottom.stl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]
2026-01-31 Changed image size to make them smaller
    [lw-pla-test-Ring.stl, lw-pla-test.FCStd, overture_pla_air_test.3mf]
2026-02-06 Added rear fairing to CAD file
    [Mockingbird.FCStd]
2026-02-15 Updated BOM with new items
2026-03-23 Added some documentation
    [Pod.stl, RearFairing.stl]
2026-03-30 Added setup docs
    [Mockingbird.FCStd]
2026-04-01 Updated TODO, updated .3mf files and stl files
    [Mockingbird.FCStd, POD.3mf, Pod.stl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]
2026-04-01 updated TODO
    [Mockingbird.FCStd, Pod.stl, TopFairingVTX.stl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]
2026-04-03 Updated VTX mount design
    [Mockingbird.FCStd, Pod.stl, TopFairingVTX.stl]
2026-04-06 Added camera mount, updated some parts, updated docs
    [CameraCableGuide.stl, CameraMount.stl, CarbonFiberBoomClampBottom.stl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]
2026-04-06 Updated some stuff
    [FrontFairing.stl, Mockingbird.FCStd]
2026-04-06 Updated the rear fairing
    [Mockingbird.FCStd, RearFairing.stl]
2026-04-10 Updated CAD
    [BOTTOM_FAIRING.3mf, BottomFairing.stl, Mockingbird.FCStd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]
2026-04-13 Added new images and stuff
    [Mockingbird.FCStd]
